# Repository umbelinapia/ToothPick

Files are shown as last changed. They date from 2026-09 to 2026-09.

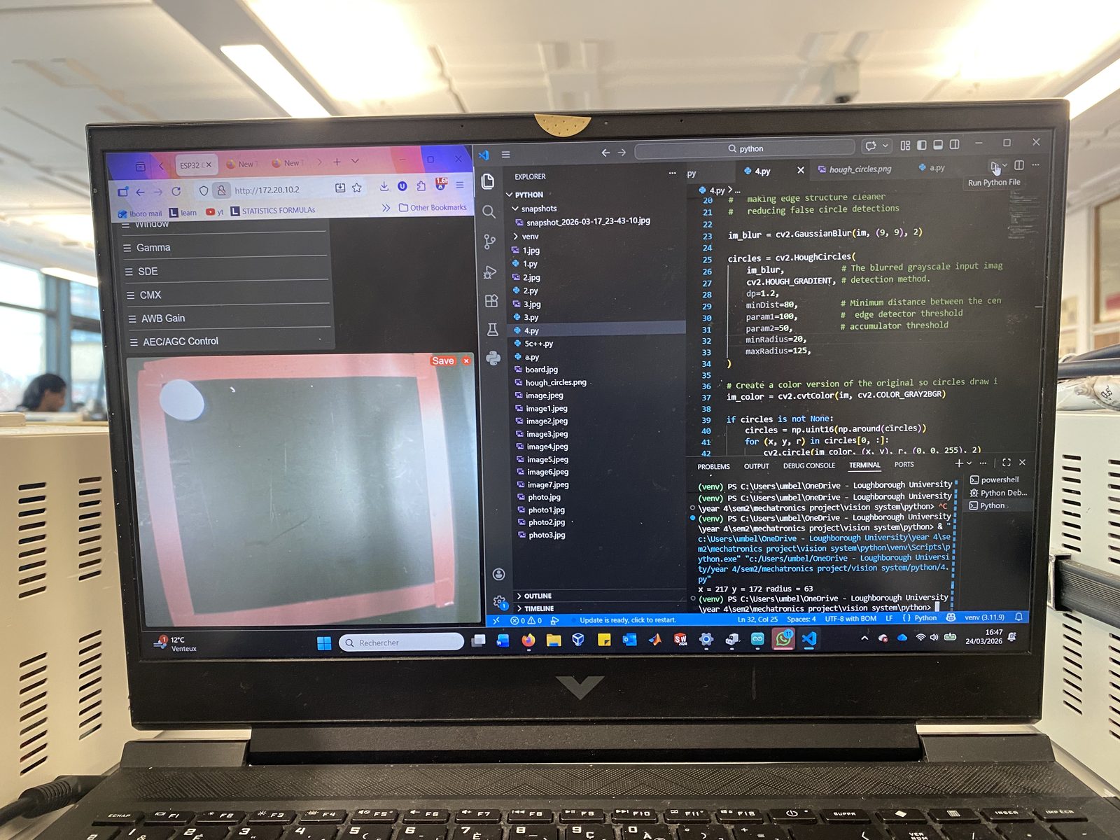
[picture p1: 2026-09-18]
evidence/photos/build-and-dev/build-03.jpg

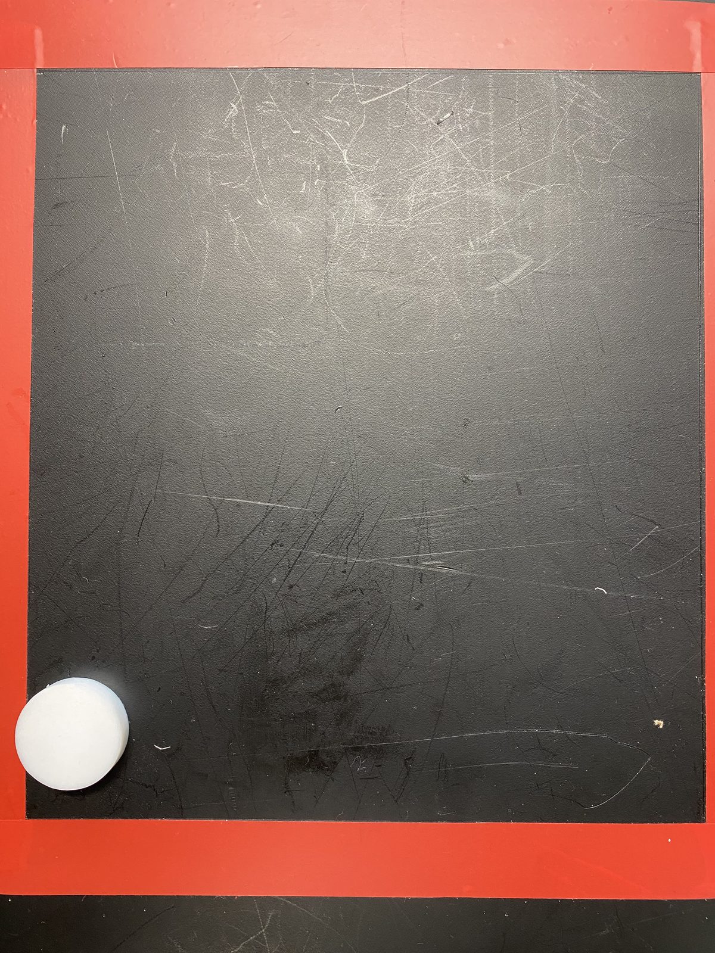
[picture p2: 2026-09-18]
evidence/photos/vision-test-captures/workspace-capture-05.jpg

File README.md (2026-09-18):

# 3rd year Mechatronics group project

## Project aim

A manufacturer's forming machine outputs plastic disc components in the
wrong orientation and an undefined location. This used to be fixed by a
worker by hand, with a 1% misorientation rate, and it's no longer safe as
the line moves to remote, unmanned automation. Our aim was to design, build,
and test an automated system that locates, flips, and places the disc
reliably, with no person in the loop.

## Project tasks

- Locate the disc using sensors (position is uncertain, so vision sensing is
  used even when not strictly required)
- Flip the disc upside down ("heads" to "tails")
- Pick up the disc and place it at a fixed destination
- Run repeatable experiments picking the disc from random starting positions

## Project objectives

- 3-DOF gantry robot built from IGUS Apiro modular drive gear units,
  controlled by an ESP32-S3
- Vision-guided disc detection (camera + OpenCV), not fixed coordinates
- Reliable, repeatable homing so every cycle starts from a known reference
- Safety interlocks so the flip/drop motions can't happen in an unsafe joint
  position
- Fast, consistent cycle time (assessed live as 4 runs in a 6-minute demo)
- Stay within the £50 build budget

## Project outcomes

Built and demonstrated a working end-to-end pipeline: home all joints, move
to a fixed camera pose, detect the disc, pick it up, home again, flip it,
move to the drop position, and place it, then reset for the next cycle. The
vision pipeline was validated against the actual part geometry (mean
diameter 25.76 mm, mean height 6.26 mm), and the full sequence was built,
tested, and demonstrated live at the Viva Voce.

## How the system works

The robot is a 3-DOF Cartesian gantry rather than an articulated arm, built
from IGUS Apiro modular drive gear units on toothed-belt rails. A gantry was
chosen over a rotary-jointed arm because each axis maps directly onto a
Cartesian/joint coordinate, so no inverse-kinematics solve is needed to
convert a target position into motor commands, which kept both the
mechanical build and the control code simpler. Three stepper motors drive
the three linear joints (J1, J2, J3), and two micro servos handle the
end-effector: one opens and closes the gripper, the other flips it between
"pick" and "drop" orientation.

**Arm control.** An ESP32-S3 runs the low-level motion firmware. Each joint
is homed against a physical limit switch before every cycle, so the robot
always starts from a known, repeatable reference position rather than
trusting wherever it happened to stop last time. Each joint also has its own
step-pulse timing, tuned individually so lighter joints move quickly without
the heavier ones losing steps. On top of that sits a small text-based
command protocol read over serial: things like `home(J1)`, `coords(J2,
speed, position)`, `open()`, `close()`, `flipUp()`, `flipDown()`, and
`cameraPose()`. Every command blocks until the arm reports back `DONE` or
`ERROR: ...`, so the caller always knows exactly when a move has actually
finished. Two safety interlocks are enforced in the firmware itself, not
just in the higher-level script: the gripper can only flip when J3 is at its
true home position, and it can only drop at the destination when J1 is at
home, the only two positions where those motions are physically safe.

**Vision.** A second ESP32-S3 with a camera module serves single frames over
Wi-Fi on request. The host laptop pulls a frame, converts it to grayscale,
applies a Gaussian blur to cut down noise, and runs a Hough Circle Transform
tuned to the disc's expected radius. Exactly one circle is expected per
frame; zero or more than one is treated as a detection failure rather than
guessed at. The detected pixel coordinate is then mapped to robot-frame
coordinates using a linear transform calibrated against the physical
workspace, with an extra correction term for the fact that the camera looks
down at an angle rather than straight overhead, which otherwise skews the
mapping near the far edge of the workspace. If the mapped position falls too
close to the front edge of the workspace, a separate "edge routine" kicks in:
the gripper approaches from the side at that boundary instead of straight
down, since a normal vertical approach would risk pushing the disc off the
edge.

**Putting it together.** The host script and the arm firmware run as two
independent loops connected only by serial (plus Wi-Fi for the camera
frames). The host's loop captures an image, processes it, and once it has a
valid detection, walks through the pick sequence one command at a time:
close the gripper, home all joints, flip up, move to the camera pose,
capture and detect, move over the disc (or run the edge routine), open,
lower, grab, return to J3 home, flip down, move to the drop position while
staying raised, lower, release, raise again, and home everything ready for
the next cycle. The arm's own loop just reads one command at a time off
serial, checks it's valid, executes it, and reports back. It has no idea
what the overall task is; it only ever sees one instruction at a time. The
blocking `DONE`/`ERROR` handshake between the two is what keeps them in
lock-step despite running on separate boards.

## Repository layout

```
firmware/     Code that runs on the two ESP32-S3 boards (arm controller + camera)
software/     Host-side (laptop) vision + pick-and-place controller
hardware/     CAD (STL exports) and component datasheets
evidence/     Documentation, presentations, measurements, build/test photos and demo video
```

Each folder has its own README with the details for that part of the
project, including the build-order history behind the final code and CAD.

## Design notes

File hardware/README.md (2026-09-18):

# Hardware

3-DOF Cartesian gantry robot:

- Gearbox drivetrain (IGUS Apiro modular drive units) on toothed-belt rails
- 3 stepper motors (joints J1/J2/J3) + 2 micro servos (gripper open/close, flip)
- Homing limit switches on every joint for a repeatable reference position
- **ESP32-S3-DEV2** as the main arm controller (compact, WiFi/Bluetooth, drives
  steppers + servos, exposes a serial command API, see [`../firmware/`](../firmware))
- Separate **ESP32-S3 AI camera module** (OV3660) for vision, wired to a
  stripboard to keep wiring permanent and minimise disconnects
- 3D-printed structural and end-effector parts

## In this folder

- [`cad/`](cad): STL exports of the team's own designed/printed parts,
  grouped by subsystem. See [`cad/README.md`](cad/README.md).
- [`datasheets/`](datasheets): component datasheets: MG90 servo dimensions,
  OV3660 camera sensor datasheet/specs, its onboard microphone, and the
  ESP32-S3 AI camera module itself.

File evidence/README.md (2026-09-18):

# Evidence

Project record: documentation, presentations, measurements, and photo/video
evidence of the build and testing process.

- [`documentation/`](documentation): [`tasks.md`](documentation/tasks.md),
  [`requirements.md`](documentation/requirements.md), [`gantt-chart.md`](documentation/gantt-chart.md)
  (who worked on what), and [`architecture-workflow.md`](documentation/architecture-workflow.md)
  (how the system works end to end). [`robot-control-logic.pdf`](documentation/robot-control-logic.pdf)
  is **my own slides**, the robot structure / vision / sequencing section of
  the group presentation was my individual share of the work, and is the
  source for `architecture-workflow.md`. [`presentations/`](documentation/presentations)
  holds the full team decks (Viva and project presentation).
- [`measurements/`](measurements): target-part measurement data.
- [`photos/`](photos): [`build-and-dev/`](photos/build-and-dev) (assembly,
  wiring, and live dev-session photos), [`vision-test-captures/`](photos/vision-test-captures)
  (raw camera captures used to tune disc detection), [`setup/`](photos/setup)
  (general camera/workspace setup shots), plus the detection output image and
  standalone build photos.
- [`videos/`](videos): a full pick, flip, place cycle demo.

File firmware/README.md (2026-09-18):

# Firmware

Code that runs directly on the two ESP32-S3 microcontrollers.

- [`arm-controller/`](arm-controller): drives the gantry robot, steppers,
  servos, homing, and the serial command API. See
  [`arm-controller/README.md`](arm-controller/README.md) for the final version
  vs. build-order iteration history.
- [`camera/`](camera): runs on the vision system's ESP32-S3 AI camera module.
  See [`camera/README.md`](camera/README.md).

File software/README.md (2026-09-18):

# Software

Host-side code, runs on a laptop, not on a microcontroller.

[`vision-pick-and-place/`](vision-pick-and-place): pulls a frame from the
camera firmware, detects the target disc with OpenCV, and drives the arm
firmware over serial through the full pick/flip/drop cycle. See
[`vision-pick-and-place/README.md`](vision-pick-and-place/README.md) for the
final version vs. iteration history.

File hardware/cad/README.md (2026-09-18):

# CAD

STL exports of the team's own designed/printed parts, grouped by subsystem.

- `base-and-drivetrain/`: base plate, mounting bracket, base gear, gear links
- `gripper-and-links/`: gripper, flipper, link, motor connectors
- `camera-mount/`: camera housing, mount, attachment point

Native CAD source files (SolidWorks `.sldprt`/`.sldasm`, Inventor `.prt`/`.iam`)
are kept separately rather than duplicated here. They're large, proprietary
formats that need the original CAD software to open, whereas the STL meshes
here can be viewed in any STL viewer or 3D-printing slicer.

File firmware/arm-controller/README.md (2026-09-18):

# Arm firmware

**Final:** [`final/arm_controller.ino`](final/arm_controller.ino), the
version that ran on the robot. Controls 3 stepper joints (J1/J2/J3) and 2
servos (gripper, flip) on an ESP32-S3, with per-joint homing, a serial
command API, and safety interlocks (flip only at true J3 home, drop only at
J1 home).

**Iterations** (`iterations/`, in build order), kept for the project record:

| Folder | What it was |
|---|---|
| `01_motor_test` | First single-motor step/pulse test |
| `02_motor_test_success` | Confirmed-working version of the same test |
| `03_umbelina_version` | First full arm sketch: joint definitions, calibration notes |
| `04_calibration` | Calibration pass on joint travel limits |
| `05_camera_serial` | Added the camera-pose move + serial handshake |
| `06_speed_test` | Experiment tightening step-pulse timing for faster motion |
| `07_umbelina_version_2` | Expanded control logic, more commands |
| `08_this_worksish` | First version with the full pick/flip/drop command set working |
| `09_umbelina_version_3` | Refined version, closest predecessor to final |
| `10_serial_heartbeat_stub` | Minimal serial "Ready/Looping" test stub, used to debug the serial link in isolation |

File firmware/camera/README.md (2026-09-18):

# Camera firmware

Runs on the vision system's ESP32-S3 AI camera module (separate board from
the arm controller).

- **`CameraWebServer.ino`**: the version actually used on the robot. Serves
  a `/capture` HTTP endpoint over Wi-Fi so the host laptop
  ([`../../software/vision-pick-and-place/`](../../software/vision-pick-and-place))
  can pull a still frame on demand.
- **`image_processing_onboard_detector.ino`**: an alternative approach that
  was prototyped, doing bright-pixel centroid detection *on the camera board
  itself* instead of sending the frame to the host. The host-side OpenCV
  pipeline is what the final system used instead.

## Note

Set your own Wi-Fi SSID/password at the top of `CameraWebServer.ino` before
flashing. The camera and host laptop need to be on the same network.

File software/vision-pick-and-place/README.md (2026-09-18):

# Vision pick-and-place controller

Runs on a host laptop, talking to two ESP32-S3 boards
([`../../firmware/`](../../firmware)):

- **Final:** [`final/pick_and_place_controller.py`](final/pick_and_place_controller.py),
  pulls a frame from the camera over HTTP, runs OpenCV Hough Circle detection
  to find the disc, maps its pixel position to robot coordinates, and drives
  the arm ([`../../firmware/arm-controller/final/arm_controller.ino`](../../firmware/arm-controller/final/arm_controller.ino))
  over serial through the full pick/flip/drop cycle.

## Iteration history

`iterations/` (numbered in build order) is the path from "can we grab a frame
and see anything" to the final integrated controller:

- `01` to `03`: basic HTTP capture from the ESP32 camera
- `04` to `07`: first circle/blob detection experiments
- `08`: scratch/draft file
- `09` to `10`: vision detection wrapped in a repeatable loop
- `11` to `12`: vision loop wired up to serial commands to the arm
- `13`: full automated infinite-loop version, immediate predecessor of
  `final/pick_and_place_controller.py`

## Detection results

[`../../evidence/photos/hough-circles-detection-output.png`](../../evidence/photos/hough-circles-detection-output.png)
is a real output frame from the detection pipeline (circle found and
annotated). [`../../evidence/photos/vision-test-captures/`](../../evidence/photos/vision-test-captures)
holds the raw top-down workspace photos, with and without the target disc,
at different positions, used to develop and tune the Hough-circle parameters
(`dp`, `minDist`, `param1`/`param2`, `minRadius`/`maxRadius` in
[`final/pick_and_place_controller.py`](final/pick_and_place_controller.py)).

See [`../../evidence/documentation/architecture-workflow.md`](../../evidence/documentation/architecture-workflow.md)
for the full pipeline diagram (image acquisition → processing → detection →
coordinate transform) and the two-loop serial handshake between this script
and the arm firmware.

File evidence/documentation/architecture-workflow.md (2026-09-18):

# Architecture / workflow

Full source diagrams: [`robot-control-logic.pdf`](robot-control-logic.pdf),
**my slides**, covering the robot structure, vision system, and task
sequencing (this section of the group presentation was my share of the
work). This is also where the repo name comes from: "toothpick" was the
project's internal codename, after the toothed-rail gantry drivetrain.

## System overview

```
        PYTHON (host laptop)                          ESP32-S3 (arm)
        ─────────────────────                          ───────────────
        image acquisition  ──HTTP GET /capture──▶  ESP32-S3 AI camera
        image processing (Gaussian blur)
        object detection (Hough circles)
        pixel → robot-frame transformation
              │
              ▼
        serial command  ───────UART────────────▶  arm control loop
        (cameraPose(), home(), open(), close(),      │
         flipUp()/flipDown(), coords(J,speed,pos))    ▼
                                                  task execution:
                                                  homing, stepper/servo motion,
                                                  safety interlocks
              ◀──────────"DONE" / "ERROR: ..."────────┘
```

## Robot structure

**Gantry robot, Cartesian configuration**, chosen over an articulated arm for
simple kinematics (no inverse-kinematics solve needed since each axis maps
directly to a Cartesian/joint coordinate), straightforward screw-and-nut
assembly, and simpler cable management along the linear rails.

## Vision pipeline

ESP32-S3 AI camera (wide-angle) → online MJPEG/HTTP stream for setup and
debugging → single-frame capture on trigger → Gaussian blur → Hough circle
detection → pixel coordinates of the detected disc → transform to robot-frame
coordinates. See [`hough-circles-detection-output.png`](../photos/hough-circles-detection-output.png)
for a real detection result, and [`vision-test-captures/`](../photos/vision-test-captures)
for the raw camera views used to develop and validate the detection routine.

## Task sequencing (two independent event loops, joined by serial + shared Wi-Fi)

**Python `loop()` (host):**
capture image → process image → cylinder detected? → no: return a warning and
retry → yes: get coordinates → execute task (send the serial command sequence
for pick/flip/place).

**Arduino `loop()` (arm):**
read serial input → is it one valid, recognised command? → no: return an
error over serial → yes: execute the command and report `DONE`.

This request/acknowledge handshake (host blocks on `DONE`/`ERROR` per command,
see `wait_for_done()` in [`pick_and_place_controller.py`](../../software/vision-pick-and-place/final/pick_and_place_controller.py))
is what keeps the two independently-running loops in lock-step despite
running on separate microcontrollers connected only by serial + a shared Wi-Fi
network for the camera link.

## Safety interlocks

- `flipUp()` / `flipDown()` only execute when J3 is at its true home switch
- `dropOpen()` only executes when J1 is at its home switch
- Both are enforced in firmware (`flipIsSafe()`, `dropIsSafe()` in
  [`arm_controller.ino`](../../firmware/arm-controller/final/arm_controller.ino)), not just in the host
  script, so a bug in the Python sequencing can't command an unsafe motion

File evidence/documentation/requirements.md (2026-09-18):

# Requirements

**Product goal:** reliably detect, pick, flip and place a cylindrical disc
without manual coordinate entry. Design drivers: accurate, repeatable,
simple; a stable structure; suited to the target environment.

## Identified requirements

- 3-DOF gantry robot with a gearbox drivetrain on toothed rails
- 3 stepper motors + 2 micro servo motors (gripper, flip)
- Homing system (limit switches) for a repeatable reference position on every cycle
- ESP32-S3-DEV2 controller: compact, sufficient processing headroom, WiFi/Bluetooth
- Stripboard wiring to keep wiring permanent and minimise disconnects
- Vision system able to locate the target disc and hand off coordinates to the arm
- Modular, adaptable, intuitive firmware functions (scalable to new end-effector routines)
- Stay within the £50 build budget

Target part, measured (see [`../measurements/disk-measurement-data.xlsx`](../measurements/disk-measurement-data.xlsx)):
mean diameter **25.76 mm**, mean height **6.26 mm** (5 samples).

## Sequencing rules (safety/consistency)

- Flipping the end-effector is only permitted when J3 is at its true home position
- Dropping (opening the gripper at the drop point) is only permitted when J1 is at home
- Every serial command blocks until the arm reports `DONE`, so each movement
  completes before the next is issued
- The homing routine re-establishes a repeatable reference position at the
  start and end of every cycle

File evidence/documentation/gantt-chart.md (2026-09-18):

# Gantt chart

Task breakdown and ownership

## Preliminary

| Task | Responsible |
|---|---|
| Success criteria definition | All |
| Workspace dimensions definition | All |
| Disc specifications definition | All |
| Requirements identification | Umbelina |
| Gantt chart | Umbelina |
| Task repartition | Umbelina |
| Camera selection | Umbelina |
| Bill of materials | All |

## Mechanical

| Task | Responsible |
|---|---|
| Layout definition vs. workspace | Umbelina |
| Arm architecture selection | Umbelina |
| Link length calculations | Umbelina |
| Reachability analysis | Umbelina |
| Flip mechanism concept design | Max |
| Gripper type selection | Max |
| Gripper CAD design | Max |
| Mounting CAD design | Max |
| CAD → print | Max |
| Order parts | Umbelina |
| Assembly | Umbelina |

## Electrical

| Task | Responsible |
|---|---|
| Power requirement calculation | Nikitha |
| Power supply selection | Nikitha |
| ESP32 configuration | Nikitha |
| End-effector actuator driver | Nikitha |
| Sensor selection | Nikitha |
| Wiring diagram | Max |
| Wiring | Umbelina |
| Cable management | Umbelina |
| Safety switch integration | Max |

## Software

| Task | Responsible |
|---|---|
| ESP32 environment setup | Nikitha |
| Motor driver interface code | Nikitha |
| Encoder reading | Nikitha |
| Joint limit implementation | Umbelina |
| Motion profiling / speed tuning | Umbelina |
| Joint control (fkine) | Umbelina |
| Kinematics (ikine) | Umbelina |
| Trajectory planning | Umbelina |
| Pick sequence routine | Umbelina |
| Flip sequence routine | Umbelina |
| Place sequence routine | Umbelina |
| Flip/drop safety interlocks (home-position gating) | Umbelina |
| Camera calibration | Umbelina |
| Workspace calibration (pixel → mm transform) | Umbelina |
| Disc detection algorithm | Umbelina |
| Coordinate transformation to robot frame | Umbelina |
| Edge-case pick routine (disc near workspace boundary) | Umbelina |

## Testing

| Task | Responsible |
|---|---|
| Single-joint test | All |
| Multi-joint coordinated motion test | All |
| Dry run without disc | All |
| Pick test | All |
| Flip test | All |
| Full pipeline test | All |

## Validation

| Task | Responsible |
|---|---|
| Accuracy measurement | Daniel |
| Flip success rate measurement | Daniel |
| Cycle time measurement | Daniel |
| System limitations analysis | All |
| Presentation preparation | All |
| Code documentation (this repo) | Umbelina |
| CAD documentation (this repo) | Umbelina |
| Oral presentation (Viva Voce) | All |

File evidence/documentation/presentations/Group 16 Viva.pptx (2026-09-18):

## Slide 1

SECTION TITLE

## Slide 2

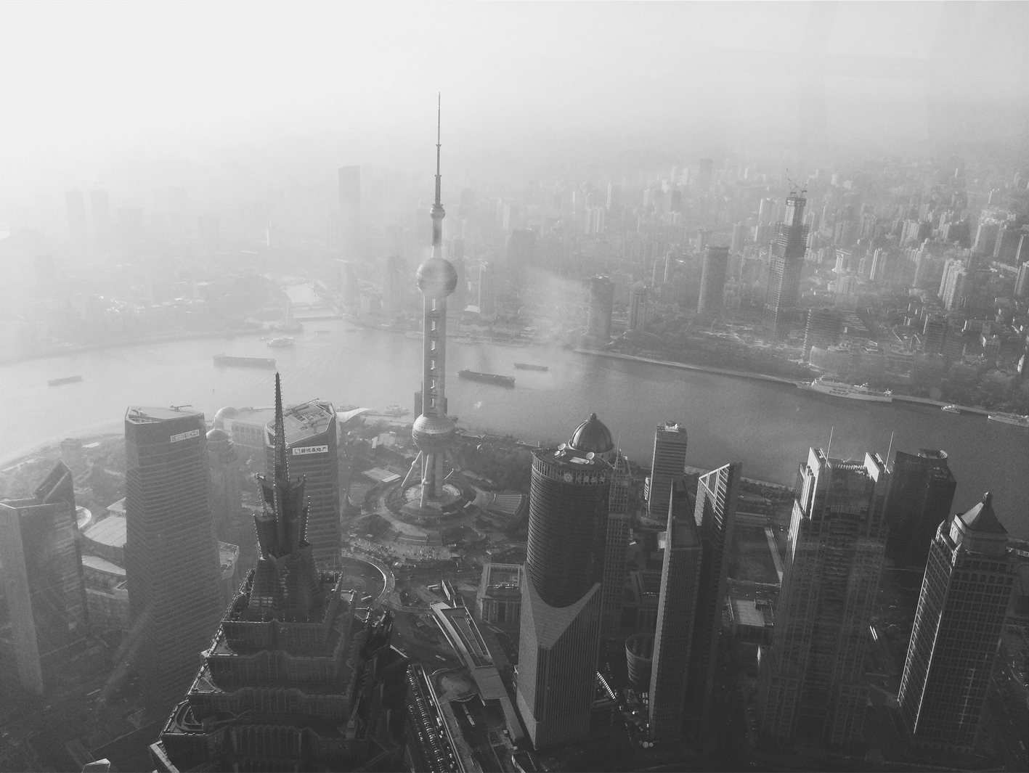
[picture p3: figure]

AUTONOMOUS CYLINDER PICK SYSTEM

CHAPTERS

PRODUCT OVERVIEW

CAMERA SEQUENCING

HARDWARE AND BASE SOFTWARE

END-EFFECTOR SEQUENCING

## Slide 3

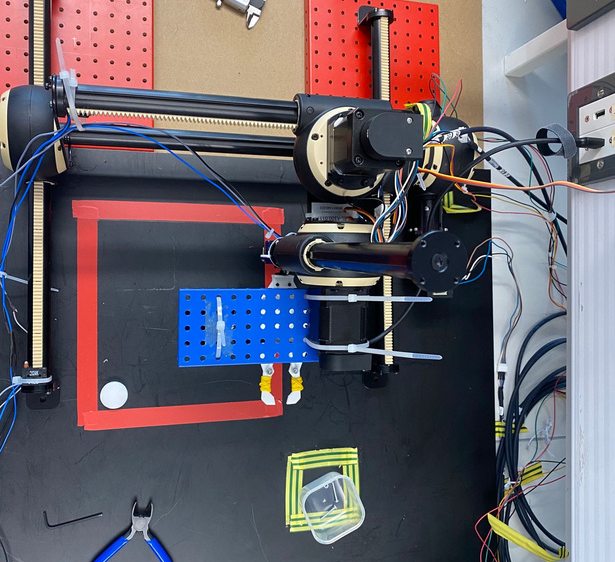
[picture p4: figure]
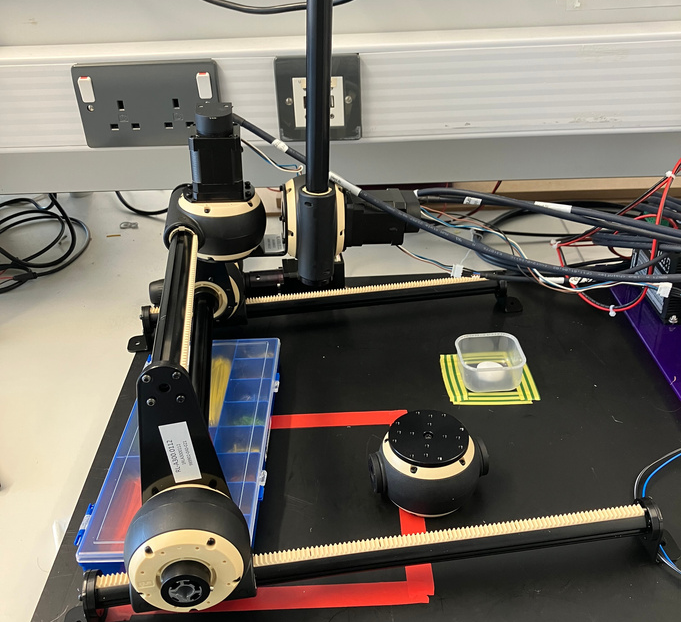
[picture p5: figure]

AUTONOMOUS CYLINDER PICK SYSTEM

OUR PRODUCT

  - 3DOF Gantry Robot
  - Gearbox with teethed rails
  - 3 Stepper Motors, 2 Servo Motors
  - Homing system

WHY?

  - Accurate, repeatable and simple
  - Stable structure
  - Ideal for environment

Daniel

caff.co

app.co

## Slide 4

Hardware and Base Software

ESP32-S3-DEV2
- Compact
- Processing Capability
- WiFi/
Bluetooth

Stripboard
- Permanent
- Less Wiring
- Minimise
Disconnect

Limit Switches
- Boundaries
- Homing

Nikitha

SECTION TWO

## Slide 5

Hardware and Base Software

2 Micro Servos
- End-Effector
- Grip and Flip

Modular Code
- Adaptable
- Intuitive
Functions
- Scalable

Homing Routine
- Consistent Positioning
- Reference

Nikitha

SECTION TWO

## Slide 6

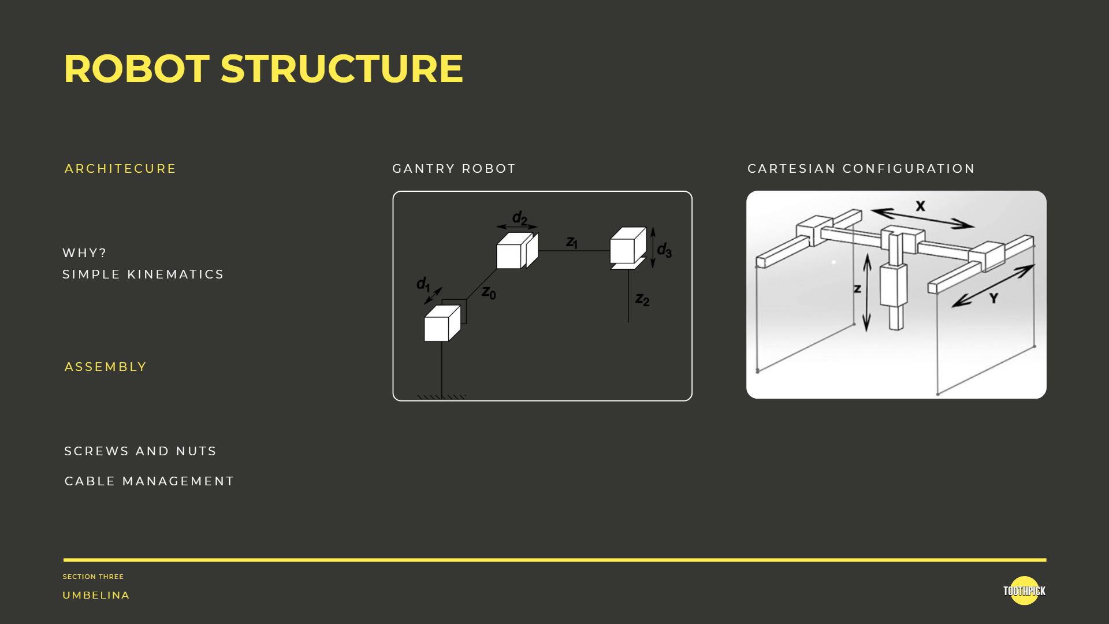
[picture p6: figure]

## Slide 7

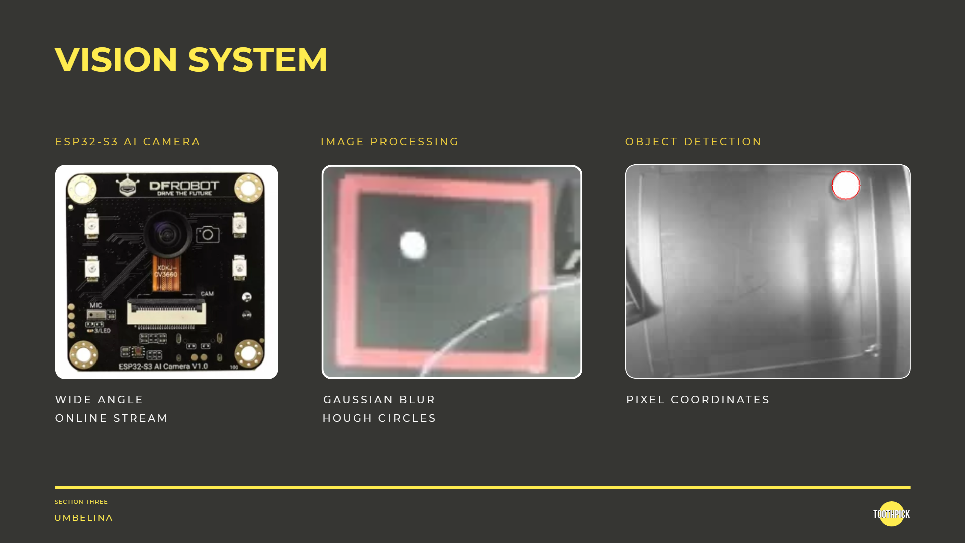
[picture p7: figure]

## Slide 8

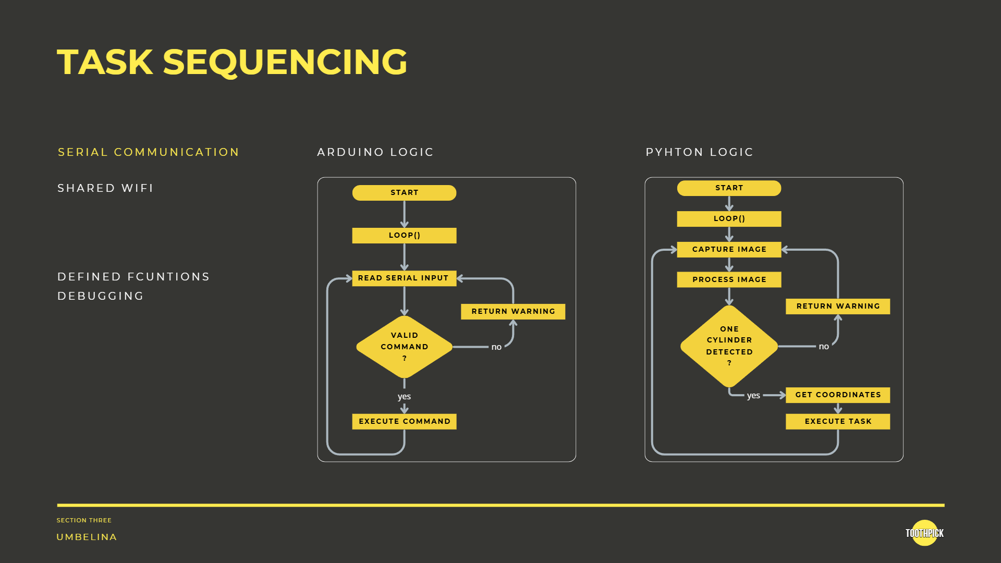
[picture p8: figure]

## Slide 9

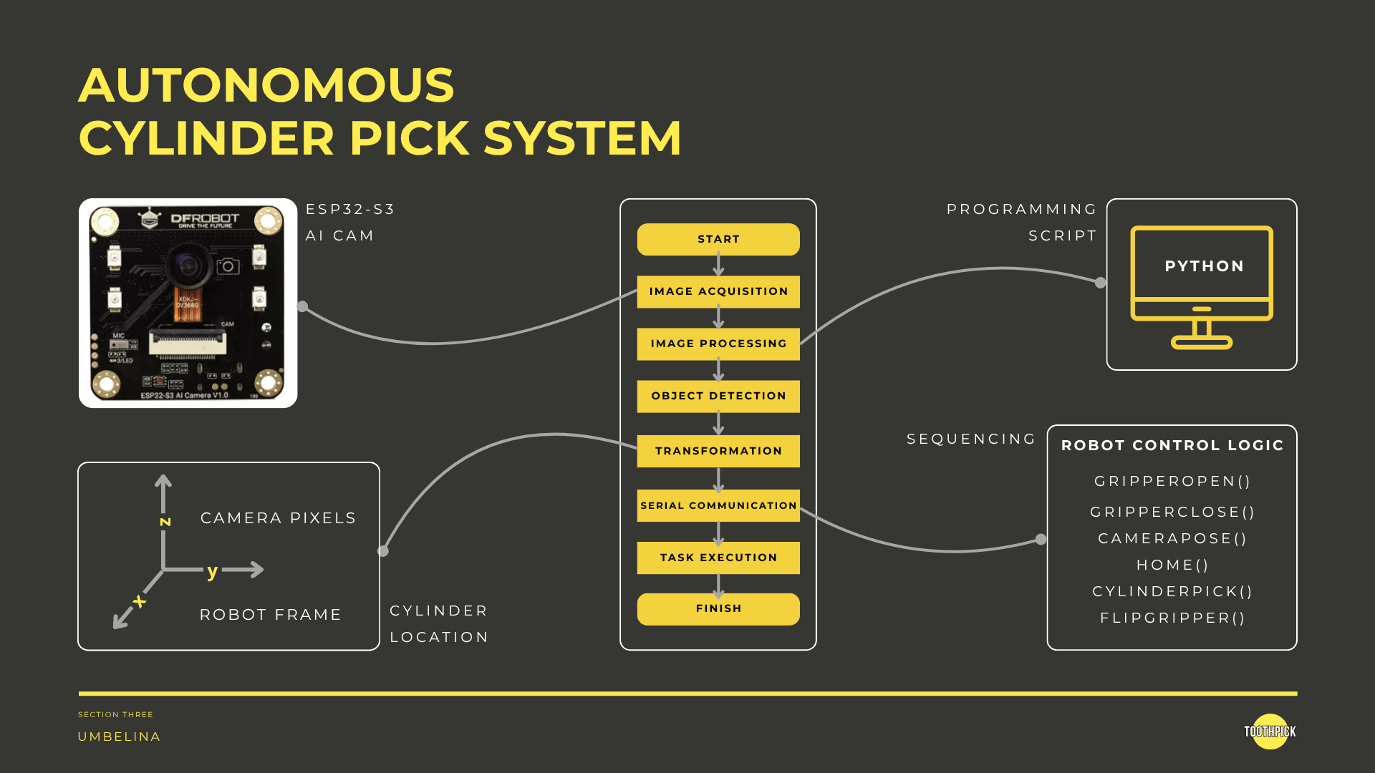
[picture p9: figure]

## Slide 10

SEQUENCE
OVERVIEW

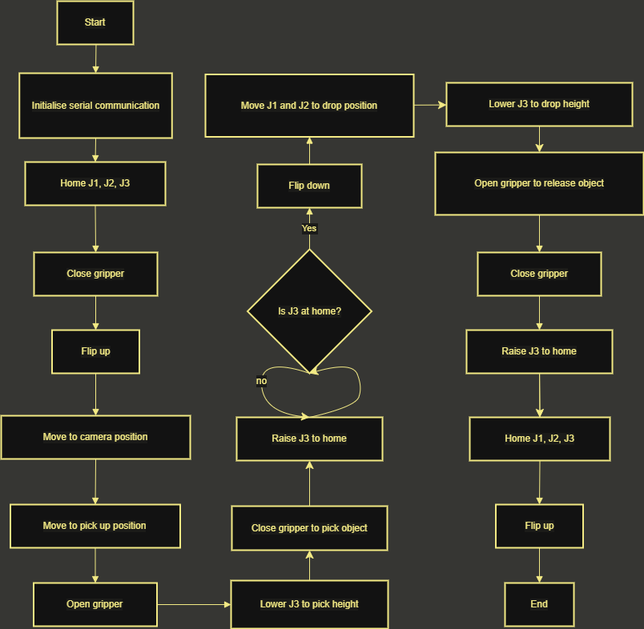
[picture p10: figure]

  - Flipping of end effector limited to when J3 is home
  - Drop limited to when J1 is at home
  - Serial ‘DONE’ ensures each movement completes before the next begins
  - Homing routine provides a repeatable reference position for every cycle

Max

SECTION FOUR

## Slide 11

End Effector

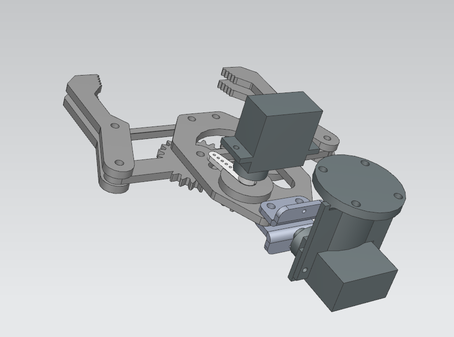
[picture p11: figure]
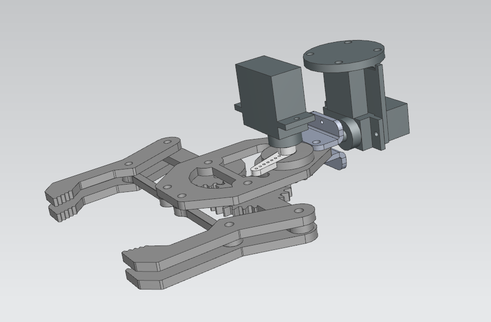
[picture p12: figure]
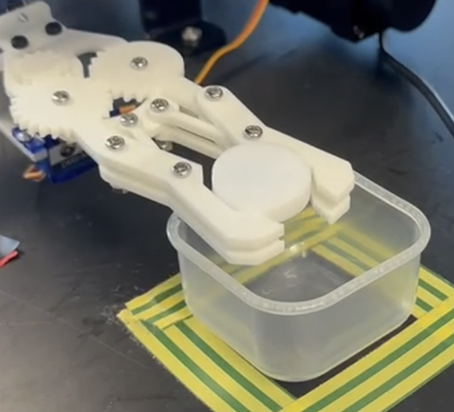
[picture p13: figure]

Max

SECTION FOUR

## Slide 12

SEE IT. PICK IT. SORT IT.

SECTION FINAL

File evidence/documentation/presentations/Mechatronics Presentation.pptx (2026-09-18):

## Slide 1

SECTION TITLE

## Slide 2


AUTONOMOUS CYLINDER PICK SYSTEM

CHAPTERS

PRODUCT OVERVIEW

CAMERA SEQUENCING

HARDWARE AND BASE SOFTWARE

END-EFFECTOR SEQUENCING

app.co

caff.co

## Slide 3


AUTONOMOUS CYLINDER PICK SYSTEM

OUR PRODUCT

  - 3DOF Gantry Robot
  - Gearbox with teethed rails
  - 3 Stepper Motors, 2 Servo Motors
  - Homing system

WHY?

  - Accurate, repeatable and simple
  - Stable structure
  - Ideal for environment

Daniel

caff.co

app.co

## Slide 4

Hardware and Base Software

ESP32-S3-DEV2
- Compact
- Processing Capability
- WiFi/
Bluetooth

Stripboard
- Permanent
- Less Wiring
- Minimise
Disconnect

nikitha

Limit Switches
- Boundaries
- Homing

SECTION TWO

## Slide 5

Hardware and Base Software

2 Micro Servos
- End-Effector
- Grip and Flip

Modular Code
- Adaptable
- Intiuitive
Functions
- Scalable

nikitha

Homing Routine
- Consistent Positioning
- Reference

SECTION TWO

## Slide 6


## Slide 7


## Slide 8


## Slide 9


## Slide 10

SEQUENCE
OVERVIEW


  - Flipping of end effector limited to when J3 is home
  - Drop limited to when J1 is at home
  - Serial ‘DONE’ ensures each movement completes before the next begins
  - Homing routine provides a repeatable reference position for every cycle

SECTION FOUR

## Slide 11

SEQUENCE
OVERVIEW


SECTION FOUR

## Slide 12

SEE IT. PICK IT. SORT IT.

SECTION FINAL

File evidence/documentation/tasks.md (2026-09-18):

# Tasks

The coursework brief (CW2, 25WSC912) set the task as: design, build, and test
a system to locate the disc, flip it upside down, and pick and place it into
a fixed destination, with sensors used to locate the disc even where its
position might otherwise be predictable, since the flip can leave it
uncertain.

Broken down for the team:

- Locate the disc using vision, not fixed coordinates
- Flip the disc upside down ("heads" to "tails")
- Pick the disc up and place it at a fixed destination
- Run repeatable experiments picking the disc from random starting positions,
  confirming the system works from an unknown start, not just a rehearsed one

Who worked on which part of the build is tracked in
[`gantt-chart.md`](gantt-chart.md).

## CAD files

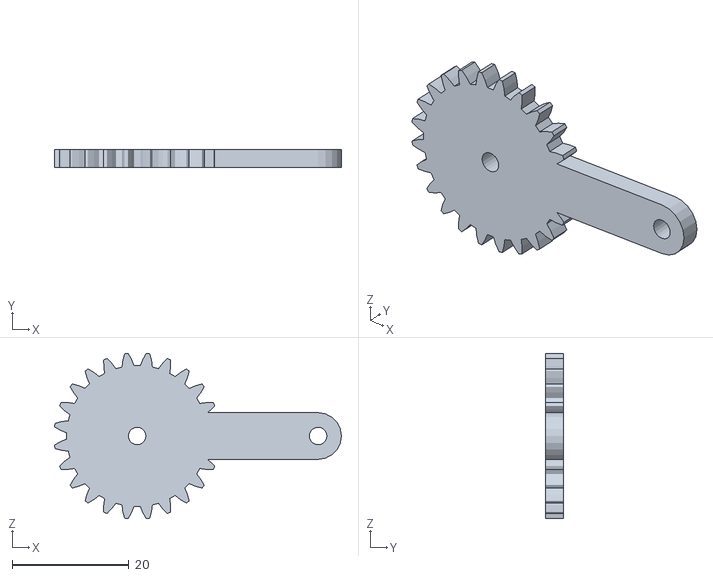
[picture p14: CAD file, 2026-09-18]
hardware/cad/stl/base-and-drivetrain/gear-link-1.stl
49.2 x 3.00 x 28.3

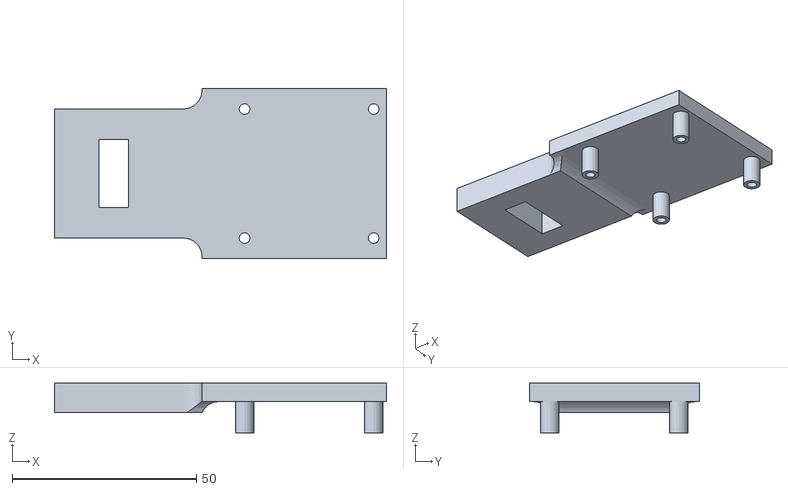
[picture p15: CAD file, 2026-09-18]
hardware/cad/stl/camera-mount/camera-housing.stl
90.0 x 46.0 x 13.5

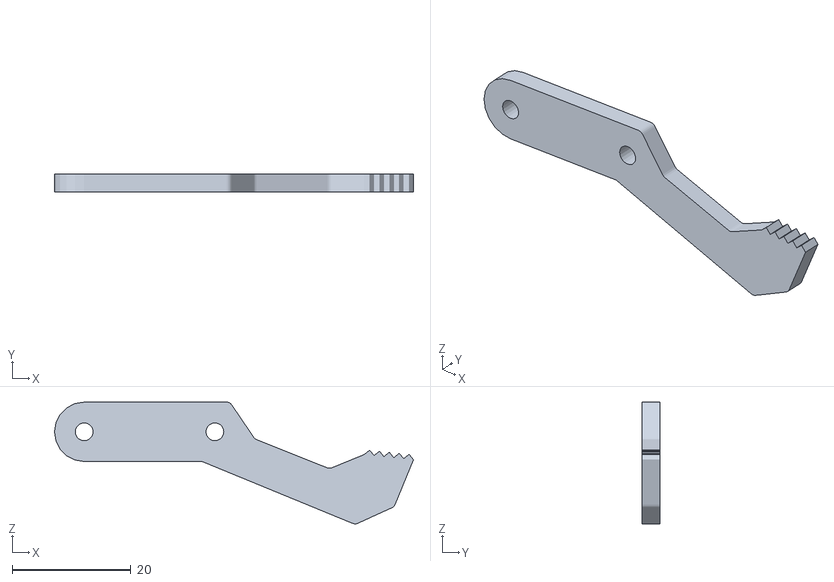
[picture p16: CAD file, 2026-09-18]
hardware/cad/stl/gripper-and-links/gripper.stl
60.4 x 3.00 x 20.5

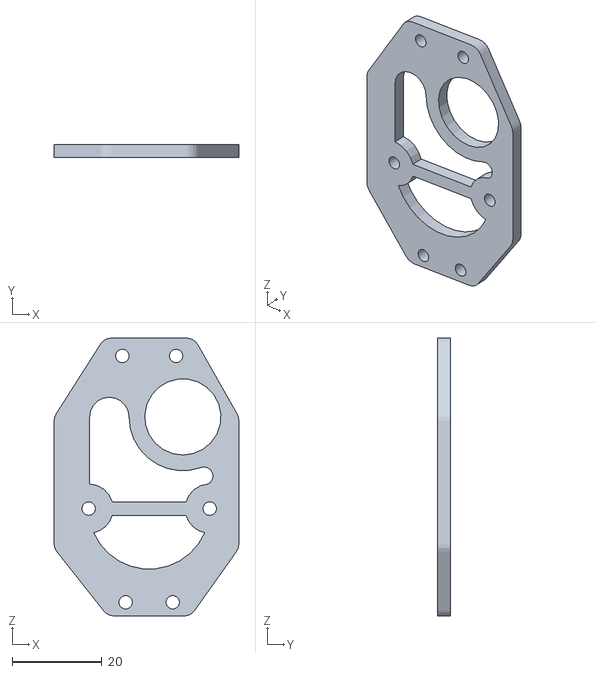
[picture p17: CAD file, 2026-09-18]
hardware/cad/stl/base-and-drivetrain/base-plate.stl
41.2 x 3.00 x 62.0

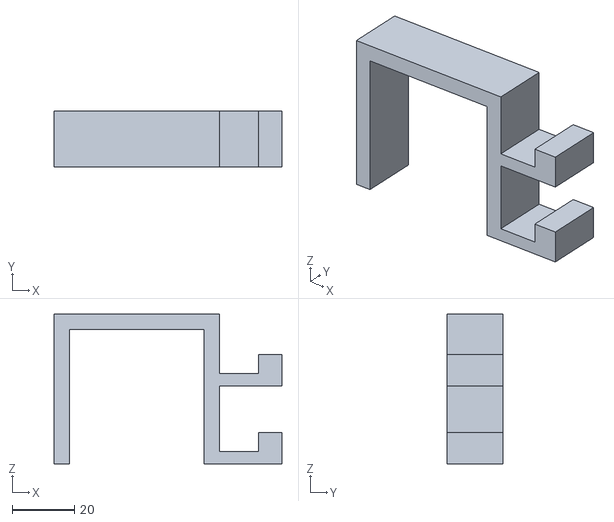
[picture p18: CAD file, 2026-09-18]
hardware/cad/stl/camera-mount/camera-mount.stl
73.0 x 18.0 x 48.0

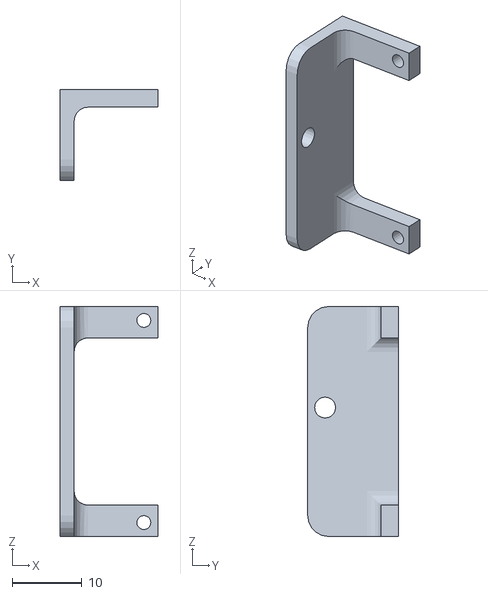
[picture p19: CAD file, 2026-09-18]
hardware/cad/stl/gripper-and-links/motor-flipper-connector.stl
14.0 x 13.0 x 33.0

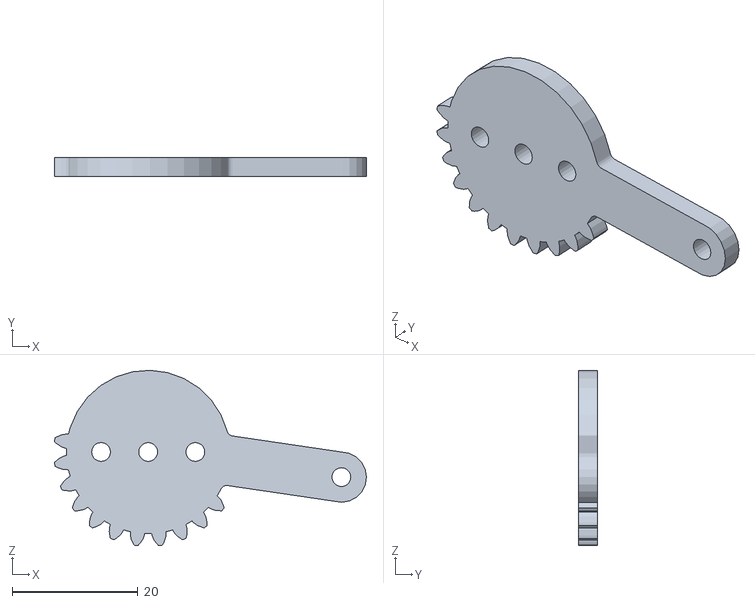
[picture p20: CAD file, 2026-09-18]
hardware/cad/stl/base-and-drivetrain/gear-link-2.stl
49.6 x 3.00 x 27.9

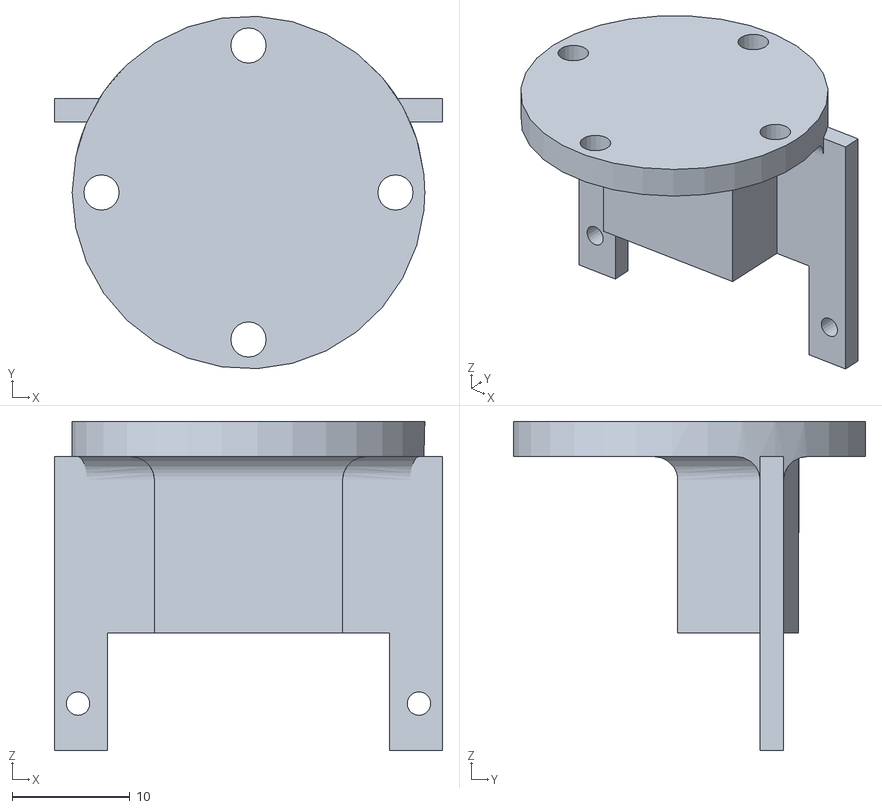
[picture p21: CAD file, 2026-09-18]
hardware/cad/stl/camera-mount/attachment-point.stl
33.0 x 30.0 x 28.0

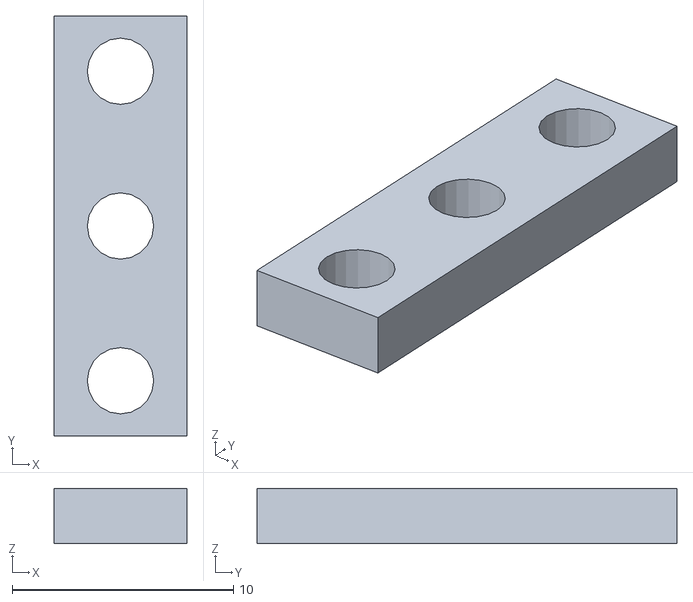
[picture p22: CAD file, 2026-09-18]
hardware/cad/stl/gripper-and-links/flipper.stl
6.00 x 19.0 x 2.50

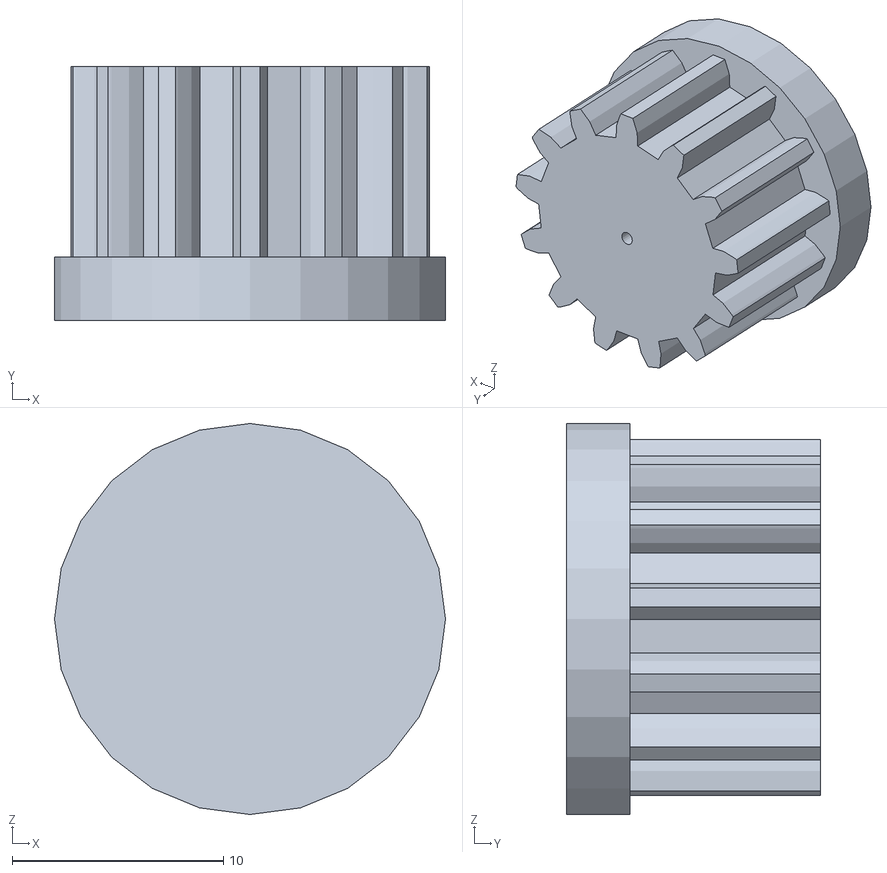
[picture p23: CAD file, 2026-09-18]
hardware/cad/stl/base-and-drivetrain/base-gear.stl
18.5 x 12.0 x 18.5

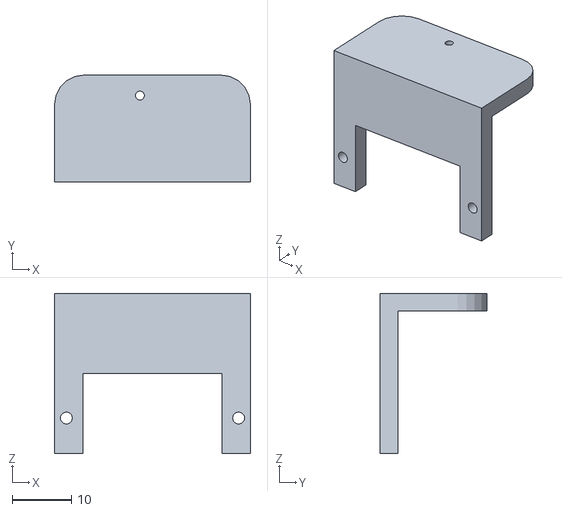
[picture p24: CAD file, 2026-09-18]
hardware/cad/stl/gripper-and-links/final-grip-motor-attach.stl
33.0 x 18.0 x 27.0

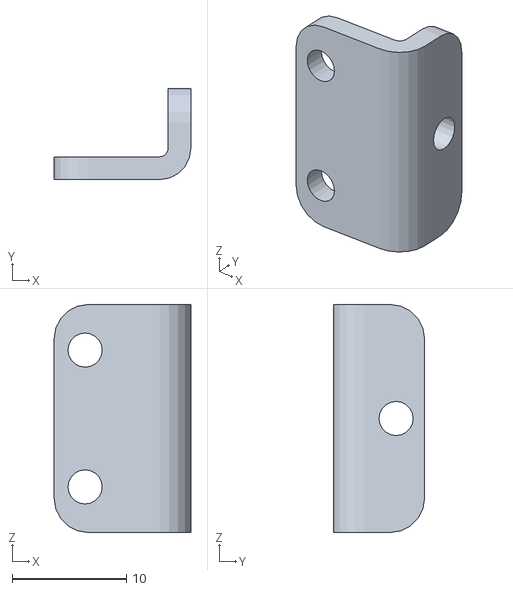
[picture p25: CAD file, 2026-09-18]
hardware/cad/stl/base-and-drivetrain/base-mounting-bracket.stl
12.0 x 8.00 x 20.0

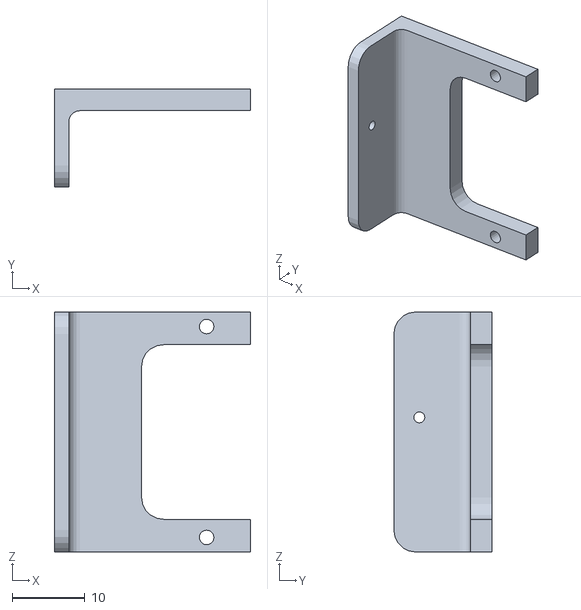
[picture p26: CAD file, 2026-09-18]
hardware/cad/stl/gripper-and-links/motor-connector.stl
27.0 x 13.5 x 33.0

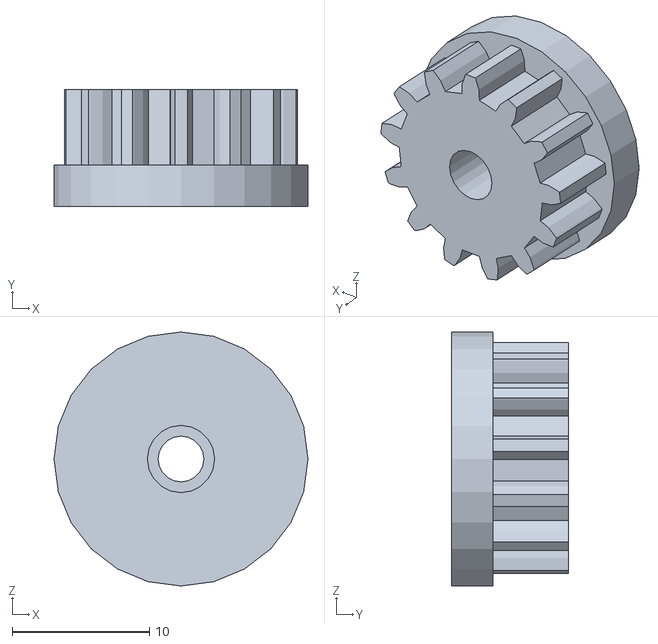
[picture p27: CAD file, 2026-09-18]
hardware/cad/stl/base-and-drivetrain/base-gear-update.stl
18.5 x 8.50 x 18.5

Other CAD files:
hardware/cad/stl/gripper-and-links/link.stl

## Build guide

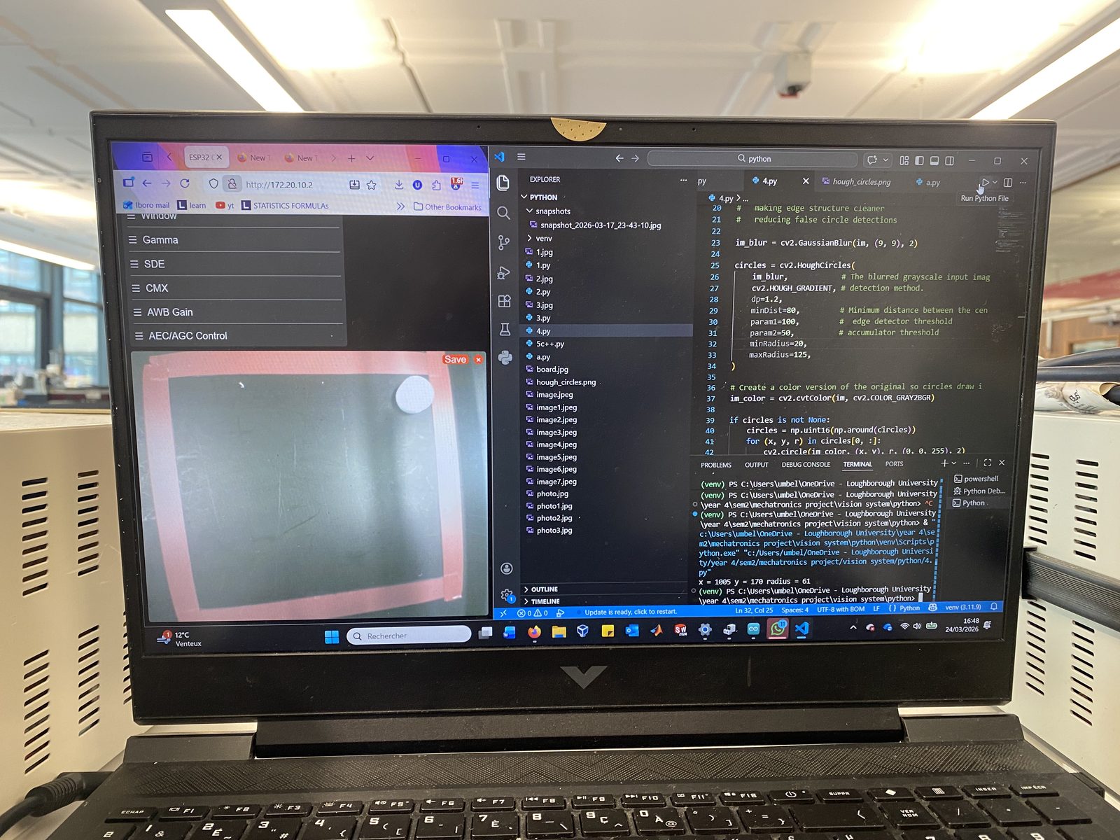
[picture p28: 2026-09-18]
evidence/photos/build-and-dev/build-06.jpg

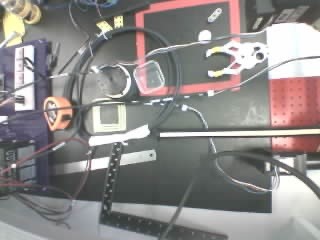
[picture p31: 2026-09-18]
evidence/photos/setup/setup-3.jpg

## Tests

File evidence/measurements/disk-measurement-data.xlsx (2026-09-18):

 | Diamiter | height
1 | 25.75 | 6.2
2 | 25.78 | 6.28
3 | 25.76 | 6.21
4 | 25.76 | 6.36
5 | 25.75 | 6.26
mean | 25.76 | 6.262

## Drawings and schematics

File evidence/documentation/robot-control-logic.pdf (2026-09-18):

# AUTONOMOUS CYLINDER PICK SYSTEM

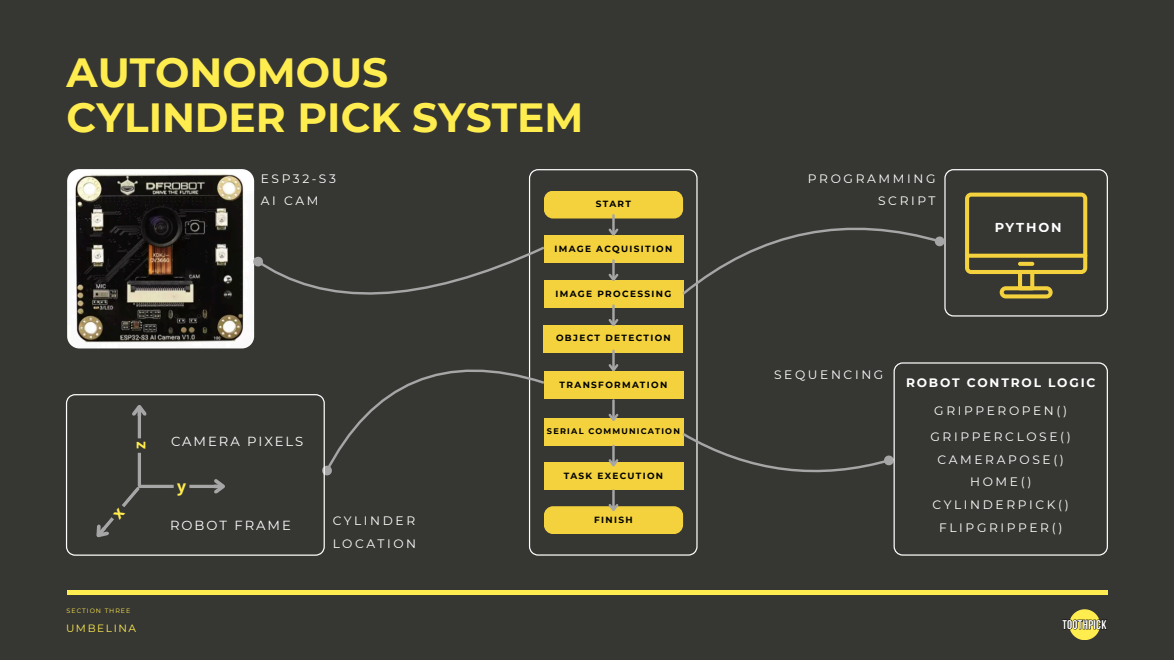
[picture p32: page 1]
START; PYT H O N; UMBEL I N A; caff.co; ttooootthhppiicckk; CAME R A PIXELS; R O B OT F R AME

IMAGE ACQ UISITI O N

IMAGE PR O C ESSI N G

O BJE CT D ETE CTI O N

T RA N SF O RMATI O N

SE R IAL COMMU N I CATI O N

TAS K E XE CUTI O N

UMBE

L I N A

# ROBOT STRUCTURE

A R C H I T E C U R E | G A N T R Y R O B O T | C A R T E S I A N C O N F I G U R A T I O N

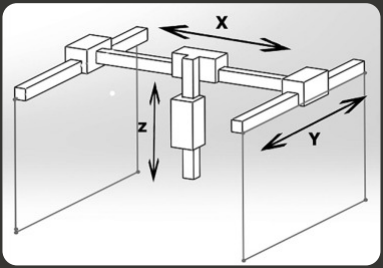
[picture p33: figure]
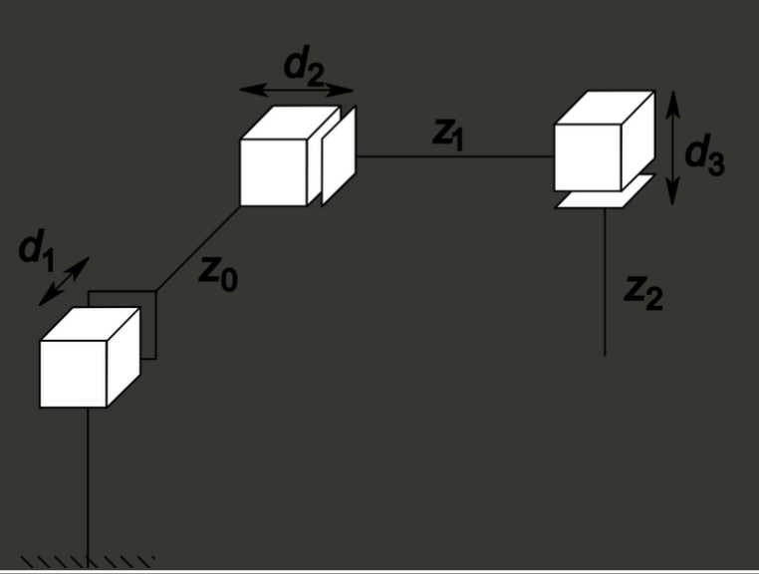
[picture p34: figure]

W H Y ?
S I M P L E K I N E M A T I C S

A S S E M B LY

S C R E W S A N D N U T S

C A B L E M A N A G E M E N T

# VISION SYSTEM

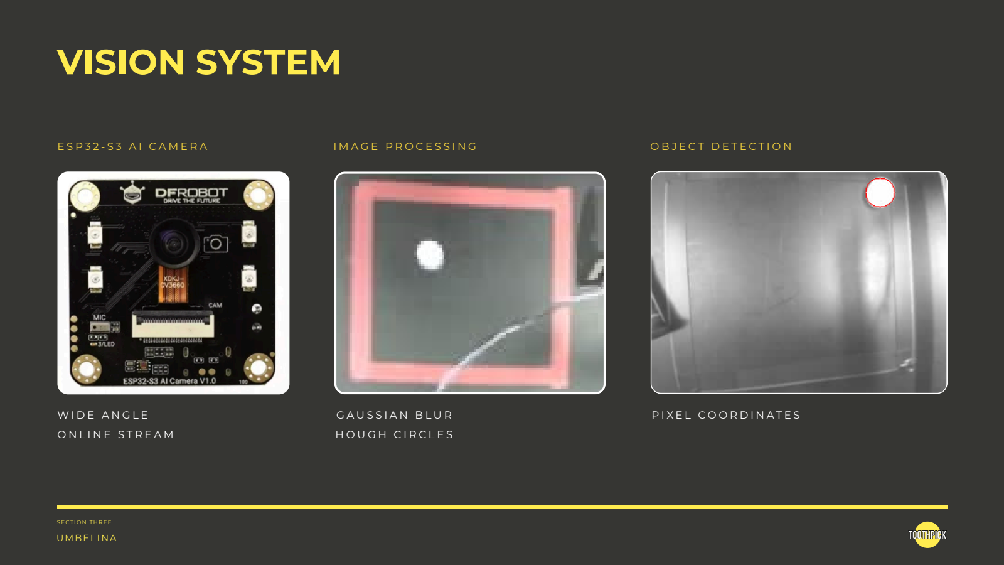
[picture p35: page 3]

UMBE

L I N A

E S P 3 2 - S 3 A I C A M E R A | I M A G E P R O C E S S I N G

G A U S S I A N B L U R
H O U G H C I R C L E S

O B J E C T D E T E C T I O N

W I D E A N G L E | P I X E L C O O R D I N A T E S
O N L I N E S T R E A M

# TASK SEQUENCING

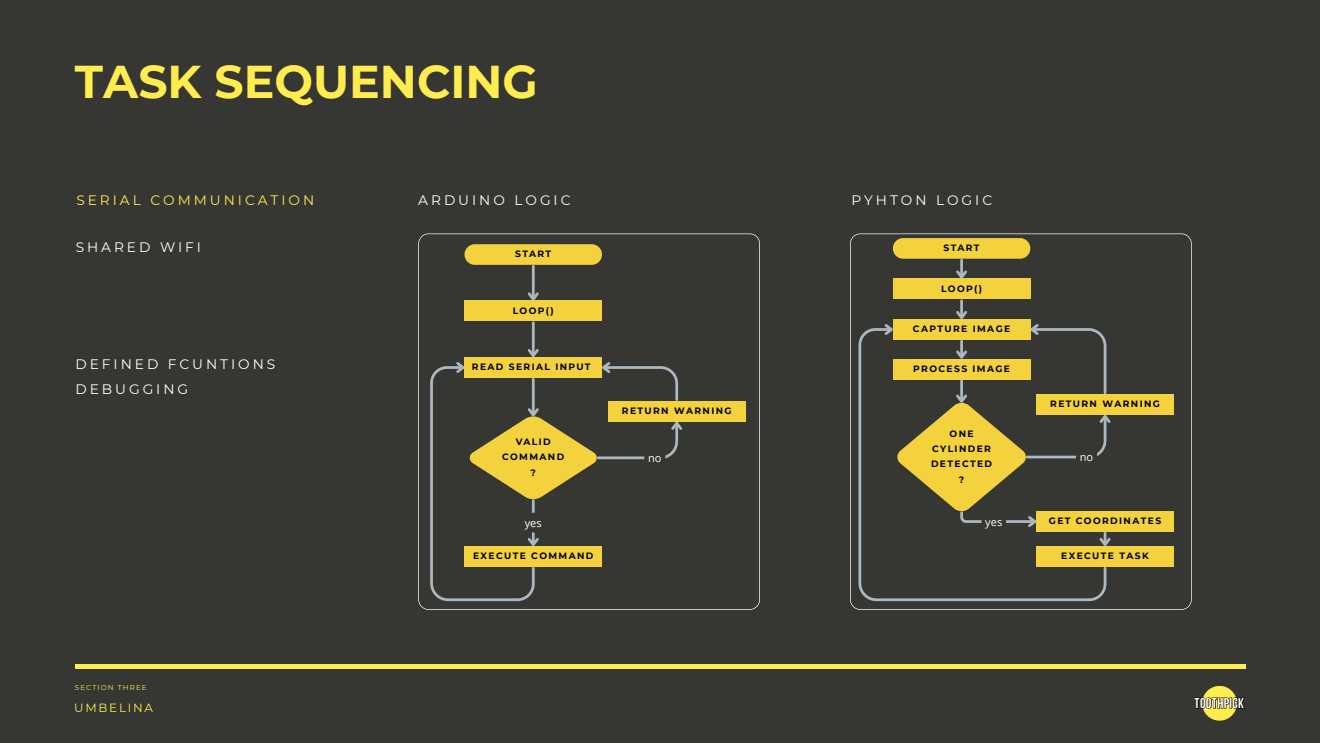
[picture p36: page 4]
UMBEL I N A; VALI D COMMA N D ?; E X E CUTE C OMMA N D; yes; START; O N E CYLI N D E R D ETE CTE D ?; E X E CUTE TAS K; P R O C ESS IMAGE; GET C O O R D I N ATES

CAP TUR E IMAGE

R EA D SE R IAL I N PUT

R ETUR N WAR N I N G

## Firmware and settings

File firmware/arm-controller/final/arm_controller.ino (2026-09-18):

#include <ESP32Servo.h>

#define PUL1 1   // J1
#define DIR1 2
#define PUL2 40  // J2
#define DIR2 39
#define PUL3 42  // J3
#define DIR3 41

#define HOME1 4
#define HOME2 5
#define HOME3 6

#define GRIP_SERVO_PIN 7
#define FLIP_SERVO_PIN 15

Servo gripServo;
Servo flipServo;

int GripOpen = 100;
int GripTightOpen = 65;
int GripClose = 0;

// Flip servo absolute positions
const int FLIP_DOWN_ANGLE = 0;
const int FLIP_UP_ANGLE   = 180;

int currentFlipAngle = FLIP_DOWN_ANGLE;

int J1_MAX = 10000;
int J2_MAX = 10150;
int J3_MAX = 700;

// Camera pose
const int CAM_J1 = 4000;
const int CAM_J2 = 8000;
const int CAM_J3 = 0;

// -----------------------------
// HOME SWITCH POLARITY
// true  = pressed reads HIGH
// false = pressed reads LOW
// -----------------------------
const bool J1_HOME_ACTIVE_HIGH = true;
const bool J2_HOME_ACTIVE_HIGH = true;
const bool J3_HOME_ACTIVE_HIGH = true;

// -----------------------------
// HOMING DIRECTION
// true  = home using motorcw()
// false = home using motorccw()
// -----------------------------
const bool J1_HOME_USES_CW = true;
const bool J2_HOME_USES_CW = true;
const bool J3_HOME_USES_CW = true;

// -----------------------------
// HOMING STEP SIZE
// -----------------------------
const int J1_HOME_STEP = 1;
const int J2_HOME_STEP = 5;
const int J3_HOME_STEP = 2;

// -----------------------------
// PER-JOINT STEP PULSE TIMING
// Bigger number = slower / gentler
// Smaller number = faster
// -----------------------------
const int J1_PULSE_US = 900;
const int J2_PULSE_US = 250;
const int J3_PULSE_US = 700;

struct Joint {
  int pul;
  int dir;
  int home;
  long pos;
  long minPos;
  long maxPos;
};

Joint J1 = {PUL1, DIR1, HOME1, 0, 0, J1_MAX};
Joint J2 = {PUL2, DIR2, HOME2, 0, 0, J2_MAX};
Joint J3 = {PUL3, DIR3, HOME3, 0, 0, J3_MAX};

String inputString = "";
bool stringComplete = false;

int getPulseDelayUs(Joint &J) {
  if (&J == &J1) return J1_PULSE_US;
  if (&J == &J2) return J2_PULSE_US;
  return J3_PULSE_US;
}

bool switchPressed(Joint &J) {
  bool activeHigh = true;

  if (&J == &J1) activeHigh = J1_HOME_ACTIVE_HIGH;
  else if (&J == &J2) activeHigh = J2_HOME_ACTIVE_HIGH;
  else if (&J == &J3) activeHigh = J3_HOME_ACTIVE_HIGH;

  int state = digitalRead(J.home);
  return activeHigh ? (state == HIGH) : (state == LOW);
}

bool jointIsHome(Joint &J) {
  return switchPressed(J);
}

void motorcw(Joint &J, int rotate) {
  int pulseUs = getPulseDelayUs(J);

  digitalWrite(J.dir, LOW);
  for (int i = 0; i < rotate; i++) {
    digitalWrite(J.pul, HIGH);
    delayMicroseconds(pulseUs);
    digitalWrite(J.pul, LOW);
    delayMicroseconds(pulseUs);
    J.pos--;
  }
}

void motorccw(Joint &J, int rotate) {
  int pulseUs = getPulseDelayUs(J);

  digitalWrite(J.dir, HIGH);
  for (int i = 0; i < rotate; i++) {
    digitalWrite(J.pul, HIGH);
    delayMicroseconds(pulseUs);
    digitalWrite(J.pul, LOW);
    delayMicroseconds(pulseUs);
    J.pos++;
  }
}

void moveTowardHome(Joint &J, int stepSize) {
  bool useCW = true;

  if (&J == &J1) useCW = J1_HOME_USES_CW;
  else if (&J == &J2) useCW = J2_HOME_USES_CW;
  else if (&J == &J3) useCW = J3_HOME_USES_CW;

  if (useCW) {
    motorcw(J, stepSize);
  } else {
    motorccw(J, stepSize);
  }
}

int getHomeStepSize(Joint &J) {
  if (&J == &J1) return J1_HOME_STEP;
  if (&J == &J2) return J2_HOME_STEP;
  return J3_HOME_STEP;
}

// Returns true only if the switch was actually reached
bool homing(Joint &J) {
  unsigned long startTime = millis();
  const unsigned long HOME_TIMEOUT_MS = 20000;
  int stepSize = getHomeStepSize(J);

  Serial.println("Starting homing...");
  Serial.print("Initial switch state: ");
  Serial.println(digitalRead(J.home));

  if (switchPressed(J)) {
    J.pos = 0;
    Serial.println("Already on home switch.");
    Serial.println("Homing complete.");
    return true;
  }

  while (!switchPressed(J)) {
    moveTowardHome(J, stepSize);

    if (millis() - startTime > HOME_TIMEOUT_MS) {
      Serial.println("ERROR: homing timeout");
      return false;
    }
  }

  J.pos = 0;

  Serial.print("Final switch state: ");
  Serial.println(digitalRead(J.home));
  Serial.println("Homing complete.");
  return true;
}

void FlipGripper(int angle) {
  flipServo.write(angle);
  currentFlipAngle = angle;
}

void GripperOpen() {
  gripServo.write(GripOpen);
}

void GripperTightOpen() {
  gripServo.write(GripTightOpen);
}

void GripperClose() {
  gripServo.write(GripClose);
}

bool coords(Joint &J, int rotate, long coord) {
  if (coord < J.minPos || coord > J.maxPos) {
    Serial.print("ERROR: target out of range. Allowed: ");
    Serial.print(J.minPos);
    Serial.print(" to ");
    Serial.println(J.maxPos);
    return false;
  }

  if (rotate <= 0) {
    Serial.println("ERROR: rotate must be > 0");
    return false;
  }

  if (J.pos == coord) return true;

  while (J.pos < coord) {
    long remaining = coord - J.pos;
    int step = (remaining > rotate) ? rotate : (int)remaining;
    motorccw(J, step);
  }

  while (J.pos > coord) {
    long remaining = J.pos - coord;
    int step = (remaining > rotate) ? rotate : (int)remaining;
    motorcw(J, step);
  }

  delay(50);
  return true;
}

bool cameraPose() {
  if (!coords(J1, 250, CAM_J1)) return false;
  if (!coords(J2, 250, CAM_J2)) return false;
  if (!coords(J3, 50, CAM_J3)) return false;
  return true;
}

Joint* getJointByName(String name) {
  name.trim();
  if (name == "J1") return &J1;
  if (name == "J2") return &J2;
  if (name == "J3") return &J3;
  return nullptr;
}

void printPositions() {
  Serial.print("J1 pos = ");
  Serial.println(J1.pos);
  Serial.print("J2 pos = ");
  Serial.println(J2.pos);
  Serial.print("J3 pos = ");
  Serial.println(J3.pos);

  Serial.print("HOME1 = ");
  Serial.println(digitalRead(HOME1));
  Serial.print("HOME2 = ");
  Serial.println(digitalRead(HOME2));
  Serial.print("HOME3 = ");
  Serial.println(digitalRead(HOME3));

  Serial.print("J1 at home = ");
  Serial.println(jointIsHome(J1) ? "YES" : "NO");
  Serial.print("J2 at home = ");
  Serial.println(jointIsHome(J2) ? "YES" : "NO");
  Serial.print("J3 at home = ");
  Serial.println(jointIsHome(J3) ? "YES" : "NO");
}

bool j1HomeSwitchPressed() {
  return switchPressed(J1);
}

bool dropIsSafe() {
  return j1HomeSwitchPressed();
}

// -----------------------------
// flipping is ONLY allowed when J3 home switch is pressed
// -----------------------------
bool flipIsSafe() {
  return jointIsHome(J3);
}

void executeCommand(String cmd) {
  cmd.trim();
  if (cmd.length() == 0) return;

  Serial.print("Received: ");
  Serial.println(cmd);

  if (cmd.startsWith("coords(") && cmd.endsWith(")")) {
    int start = cmd.indexOf('(');
    int end = cmd.lastIndexOf(')');
    String inside = cmd.substring(start + 1, end);

    int c1 = inside.indexOf(',');
    int c2 = inside.indexOf(',', c1 + 1);

    if (c1 == -1 || c2 == -1) {
      Serial.println("ERROR: invalid coords format. Use coords(J2,100,8000)");
      return;
    }

    String jointName = inside.substring(0, c1);
    String rotateStr = inside.substring(c1 + 1, c2);
    String coordStr = inside.substring(c2 + 1);

    Joint* joint = getJointByName(jointName);
    if (joint == nullptr) {
      Serial.println("ERROR: invalid joint. Use J1, J2, or J3.");
      return;
    }

    int rotate = rotateStr.toInt();
    long coord = coordStr.toInt();

    if (coords(*joint, rotate, coord)) {
      Serial.println("DONE");
    }
    return;
  }

  if (cmd.startsWith("home(") && cmd.endsWith(")")) {
    int start = cmd.indexOf('(');
    int end = cmd.lastIndexOf(')');
    String jointName = cmd.substring(start + 1, end);

    Joint* joint = getJointByName(jointName);
    if (joint == nullptr) {
      Serial.println("ERROR: invalid joint. Use J1, J2, or J3.");
      return;
    }

    if (homing(*joint)) {
      Serial.println("DONE");
    }
    return;
  }

  if (cmd == "opentight()") {
    GripperTightOpen();
    Serial.println("DONE");
    return;
  }

  if (cmd == "open()") {
    GripperOpen();
    Serial.println("DONE");
    return;
  }

  if (cmd == "dropOpen()") {
    if (!dropIsSafe()) {
      Serial.print("ERROR: drop blocked. J1 switch not pressed. HOME1 = ");
      Serial.println(digitalRead(HOME1));
      return;
    }

    GripperOpen();
    Serial.println("DONE");
    return;
  }

  if (cmd == "close()") {
    GripperClose();
    Serial.println("DONE");
    return;
  }

  if (cmd == "flipUp()") {
    if (!flipIsSafe()) {
      Serial.print("ERROR: flip blocked. J3 not at true home. HOME3 = ");
      Serial.print(digitalRead(HOME3));
      Serial.print(" J3 pos = ");
      Serial.println(J3.pos);
      return;
    }

    FlipGripper(FLIP_UP_ANGLE);
    Serial.println("DONE");
    return;
  }

  if (cmd == "flipDown()") {
    if (!flipIsSafe()) {
      Serial.print("ERROR: flip blocked. J3 not at true home. HOME3 = ");
      Serial.print(digitalRead(HOME3));
      Serial.print(" J3 pos = ");
      Serial.println(J3.pos);
      return;
    }

    FlipGripper(FLIP_DOWN_ANGLE);
    Serial.println("DONE");
    return;
  }

  if (cmd == "flip()") {
    if (!flipIsSafe()) {
      Serial.print("ERROR: flip blocked. J3 not at true home. HOME3 = ");
      Serial.print(digitalRead(HOME3));
      Serial.print(" J3 pos = ");
      Serial.println(J3.pos);
      return;
    }

    if (currentFlipAngle == FLIP_UP_ANGLE) {
      FlipGripper(FLIP_DOWN_ANGLE);
    } else {
      FlipGripper(FLIP_UP_ANGLE);
    }

    Serial.println("DONE");
    return;
  }

  if (cmd == "pos()") {
    printPositions();
    Serial.println("DONE");
    return;
  }

  if (cmd == "cameraPose()") {
    if (cameraPose()) {
      Serial.println("DONE");
    }
    return;
  }

  Serial.println("ERROR: unknown command");
}

void readSerialInput() {
  while (Serial.available()) {
    char inChar = (char)Serial.read();

    if (inChar == '\n' || inChar == '\r') {
      if (inputString.length() > 0) {
        stringComplete = true;
      }
    } else {
      inputString += inChar;
    }
  }
}

void setup() {
  pinMode(PUL1, OUTPUT);
  pinMode(DIR1, OUTPUT);
  pinMode(PUL2, OUTPUT);
  pinMode(DIR2, OUTPUT);
  pinMode(PUL3, OUTPUT);
  pinMode(DIR3, OUTPUT);

  pinMode(HOME1, INPUT_PULLUP);
  pinMode(HOME2, INPUT_PULLUP);
  pinMode(HOME3, INPUT_PULLUP);

  Serial.begin(115200);
  delay(3000);
  Serial.println("Ready.");

  gripServo.attach(GRIP_SERVO_PIN, 500, 2400);
  flipServo.attach(FLIP_SERVO_PIN, 500, 2400);

  GripperOpen();
  FlipGripper(FLIP_DOWN_ANGLE);

  inputString.reserve(100);

  Serial.println("Commands:");
  Serial.println("  open()");
  Serial.println("  dropOpen()");
  Serial.println("  close()");
  Serial.println("  flipUp()");
  Serial.println("  flipDown()");
  Serial.println("  flip()");
  Serial.println("  home(J1)");
  Serial.println("  home(J2)");
  Serial.println("  home(J3)");
  Serial.println("  coords(J2,100,8000)");
  Serial.println("  cameraPose()");
  Serial.println("  pos()");
  Serial.println("DONE is only printed on real success.");
}

void loop() {
  readSerialInput();

  if (stringComplete) {
    executeCommand(inputString);
    inputString = "";
    stringComplete = false;
  }
}

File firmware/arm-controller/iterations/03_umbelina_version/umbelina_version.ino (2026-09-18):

//Nikitha Prabhakar
//20/03/26
//Caqlliobration

//30-1.7 j1
//30-12= ? 17.5? j2
//9.8- 0.5 j3

/*motorccw(J1, 9250);
  motorccw(J2, 9250);
  motorccw(J3, 1200);*/
#include <ESP32Servo.h>

#define PUL1 1 //J1
#define DIR1 2
#define PUL2 40 //J2
#define DIR2 39
#define PUL3 42 //J2
#define DIR3 41

#define HOME1 4
#define HOME2 5
#define HOME3 6

#define GRIP_SERVO_PIN 7
#define FLIP_SERVO_PIN 15

Servo gripServo;
Servo flipServo;

bool flipState = false;

int rotate = 0;
int FlipHome = 0;
int FlipAngle = 180;
int GripOpen = 0;
int GripClose = 180;

int J1_MAX = 10000;
int J2_MAX = 10150;
int J3_MAX = 625;

const int CAM_J1 = 3750;
const int CAM_J2 = 8000;
const int CAM_J3 = 0;


struct Joint {
  int pul;
  int dir;
  int home;
  long pos;
  long minPos;
  long maxPos;
};

Joint J1 = {PUL1, DIR1, HOME1, 0, 0, J1_MAX};
Joint J2 = {PUL2, DIR2, HOME2, 0, 0, J2_MAX};
Joint J3 = {PUL3, DIR3, HOME3, 0, 0, J3_MAX};

//delete
String inputString = "";
bool stringComplete = false;

void setup() {
  pinMode(PUL1, OUTPUT);
  pinMode(DIR1, OUTPUT);
  pinMode(PUL2, OUTPUT);
  pinMode(DIR2, OUTPUT);
  pinMode(PUL3, OUTPUT);
  pinMode(DIR3, OUTPUT);
  pinMode(HOME1, INPUT);
  pinMode(HOME2, INPUT);
  pinMode(HOME3, INPUT);

  Serial.begin(115200);

  gripServo.attach(GRIP_SERVO_PIN, 500, 2400);
  flipServo.attach(FLIP_SERVO_PIN, 500, 2400);

  inputString.reserve(100);

  Serial.println("Ready.");
  Serial.println("Example commands:");
  Serial.println("coords(J2,100,8000)");
  Serial.println("home(J1)");
  Serial.println("open()");
  Serial.println("close()");
  Serial.println("flip()");
  Serial.println("pos()");
}

//motorcw(J1, 100)
void motorcw(Joint &J,int rotate) {
  //direction LOW is Clockwise
  //direction HIGH is Anti-clockwise
  digitalWrite(J.dir, LOW);

  //pulse is the control signal
  for (int i = 0; i < rotate; i++) {
    digitalWrite(J.pul, HIGH);
    delayMicroseconds(500);
    digitalWrite(J.pul, LOW);
    delayMicroseconds(500);
    J.pos--;
  }
}

//motorccw(J1, 100)
void motorccw(Joint &J,int rotate) {
  //direction LOW is Clockwise
  //direction HIGH is Anti-clockwise
  digitalWrite(J.dir, HIGH);

  //pulse is the control signal
  for (int i = 0; i < rotate; i++) {
    digitalWrite(J.pul, HIGH);
    delayMicroseconds(500);
    digitalWrite(J.pul, LOW);
    delayMicroseconds(500);
    J.pos++;
    Serial.println(J.pos);
  }
}

//homing(J1, 100)
void homing(Joint &J,int rotate) {
  while (digitalRead(J.home) == LOW){
    Serial.println(digitalRead(J.home));
    motorcw(J, rotate);
    
  }
  J.pos = 0;

}



//enc_cal(J1, 100, CountA1);
void pos_cal(Joint &J,int rotate, volatile long &count) {
  count = 0;
  motorcw(J, rotate);
  Serial.print("rotations: ");
  Serial.println(rotate);
}

// FlipGripper()
void FlipGripper() {
  if (flipState == false) {
    flipServo.write(FlipAngle);
    flipState = true;
  } else {
    flipServo.write(FlipHome);
    flipState = false;
  }
}

//GripperOpen()
void GripperOpen(){
  gripServo.write(GripOpen);
  }

//GripperClose()
void GripperClose(){
  gripServo.write(GripClose);
  }
//set the coordinates for camera IN PROGRESS
void cameraPose(){
  coords(J1, 50, CAM_J1);
  coords(J2, 50, CAM_J2);
  coords(J3, 50, CAM_J3);
}

//coords(J1, rotations, coord for joint)
void coords(Joint &J,int rotate, int coord){
  
  if (coord < J.minPos || coord > J.maxPos) {
    Serial.print("ERROR: ");
    Serial.print(" target out of range. Allowed: ");
    Serial.print(J.minPos);
    Serial.print(" to ");
    Serial.println(J.maxPos);
    return;
  }

  while (J.pos < coord) {
    // motorccw(J, rotate);
    
    //delete
    int remaining = coord - J.pos;
    int step = (remaining > rotate) ? rotate : remaining;
    motorccw(J, step);
  }

  while (J.pos> coord){
    // motorcw(J, rotate);

    //delete
    int remaining = coord - J.pos;
    int step = (remaining > rotate) ? rotate : remaining;
    motorccw(J, step);
  }
  delay(2000);

}

//delete

Joint* getJointByName(String name) {
  name.trim();

  if (name == "J1") return &J1;
  if (name == "J2") return &J2;
  if (name == "J3") return &J3;

  return nullptr;
}

void printPositions() {
  Serial.print("J1 pos = ");
  Serial.println(J1.pos);

  Serial.print("J2 pos = ");
  Serial.println(J2.pos);

  Serial.print("J3 pos = ");
  Serial.println(J3.pos);
}

//delete
void executeCommand(String cmd) {
  cmd.trim();

  if (cmd.length() == 0) return;

  Serial.print("Received: ");
  Serial.println(cmd);

  // coords(J2,100,8000)
  if (cmd.startsWith("coords(") && cmd.endsWith(")")) {
    int start = cmd.indexOf('(');
    int end = cmd.lastIndexOf(')');
    String inside = cmd.substring(start + 1, end);

    int c1 = inside.indexOf(',');
    int c2 = inside.indexOf(',', c1 + 1);

    if (c1 == -1 || c2 == -1) {
      Serial.println("Invalid coords format. Use: coords(J2,100,8000)");
      return;
    }

    String jointName = inside.substring(0, c1);
    String rotateStr = inside.substring(c1 + 1, c2);
    String coordStr = inside.substring(c2 + 1);

    Joint* joint = getJointByName(jointName);
    if (joint == nullptr) {
      Serial.println("Invalid joint. Use J1, J2, or J3.");
      return;
    }

    int rotate = rotateStr.toInt();
    long coord = coordStr.toInt();

    coords(*joint, rotate, coord);
    return;
  }

  // home(J1)
  if (cmd.startsWith("home(") && cmd.endsWith(")")) {
    int start = cmd.indexOf('(');
    int end = cmd.lastIndexOf(')');
    String jointName = cmd.substring(start + 1, end);

    Joint* joint = getJointByName(jointName);
    if (joint == nullptr) {
      Serial.println("Invalid joint. Use J1, J2, or J3.");
      return;
    }

    homing(*joint, 10);   // smaller step size is safer for homing
    return;
  }

  // open()
  if (cmd == "open()") {
    GripperOpen();
    return;
  }

  // close()
  if (cmd == "close()") {
    GripperClose();
    return;
  }

  // flip()
  if (cmd == "flip()") {
    FlipGripper();
    return;
  }

  // pos()
  if (cmd == "pos()") {
    printPositions();
    return;
  }

  if (cmd == "cameraPose()") {
    cameraPose();
    return;
  }
  Serial.println("Unknown command.");
}

//delete
void readSerialInput() {
  while (Serial.available()) {
    char inChar = (char)Serial.read();

    if (inChar == '\n' || inChar == '\r') {
      if (inputString.length() > 0) {
        stringComplete = true;
      }
    } else {
      inputString += inChar;
    }
  }
}


void loop() {
  readSerialInput();

  if (stringComplete) {
    executeCommand(inputString);
    inputString = "";
    stringComplete = false;
  }
}

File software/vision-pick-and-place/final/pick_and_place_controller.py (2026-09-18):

import time
import serial

# Standard imports
import os
import cv2
import numpy as np

import requests
from datetime import datetime
from pathlib import Path

# convert coordinates
def camera_to_robot(xc, yc):
    xc = float(xc)
    yc = float(yc)

    # clamp camera values
    xc = max(30.0, min(250.0, xc))
    yc = max(30.0, min(200.0, yc))

    print(f"Clamped camera coordinates: x={xc}, y={yc}")

    xr = 2500.0 + (xc - 30.0) * 4500.0 / 220.0
    yr = (yc - 30.0) * 7000.0 / 170.0
    
    print(f"Mapped robot coordinates: x={int(round(xr))}, y={int(round(yr))}")

    # deduction
    t = (200.0 - yc) / 185.0
    y_deduction = 1000.0 * (t ** 0.8)

    yr -= y_deduction

    #y_deduction = 250.0 * (200.0 - yc) / 185.0
    #yr = yr - 250.0
    
    yr = max(0.0, min(7000.0, yr))
    print(f"Mapped deducted robot coordinates: x={int(round(xr))}, y={int(round(yr))}")

    return int(round(xr)), int(round(yr))

# get image from ESP32
ESP32_URL = "http://172.20.10.2/capture"


# hough_out = "hough_circles.png"
# cv2.imwrite(hough_out, im_color)



SERIAL_PORT = "COM10"
BAUD_RATE = 115200
TIMEOUT = 40

# -----------------------------
# SPEEDS
# -----------------------------
J1_SPEED = 250
J2_SPEED = 300
J3_SPEED = 25

# -----------------------------
# IMPORTANT POSITIONS
# Change these easily later
# -----------------------------
J3_PICK_DOWN = 700
J3_DROP_HEIGHT = 100
J3_HOME_UP = 0

CAM_J1 = 4000
CAM_J2 = 7500
CAM_J3 = 0

DROP_J2 = 10150

# -----------------------------
# DELAYS
# -----------------------------
START_DELAY = 1.0
OPEN_DELAY = 1.0
DOWN_DELAY = 1.0
GRAB_DELAY = 1.0
LIFT_DELAY = 2.0
FLIP_DELAY = 1.5
PRE_DROP_DELAY = 1.0
DROP_DELAY = 1.0
POST_DROP_CLOSE_DELAY = 0.5
POST_DROP_LIFT_DELAY = 1.5
HOME_DELAY = 1.0
FINAL_DELAY = 1.0

MAX_X_ROBOT = 7150
EDGE_Y_THRESHOLD = 1000


def read_available_lines(arduino, duration=1.5):
    end_time = time.time() + duration
    while time.time() < end_time:
        while arduino.in_waiting > 0:
            line = arduino.readline().decode(errors="ignore").strip()
            if line:
                print(f"Arduino: {line}")
        time.sleep(0.02)


def wait_for_done(arduino, timeout=TIMEOUT):
    start_time = time.time()

    while time.time() - start_time < timeout:
        if arduino.in_waiting > 0:
            line = arduino.readline().decode(errors="ignore").strip()

            if line:
                print(f"Arduino: {line}")

            if line == "DONE":
                return True

            if line.startswith("ERROR"):
                raise RuntimeError(line)

        time.sleep(0.02)

    raise TimeoutError("Timed out waiting for Arduino DONE response")


def send_command(arduino, cmd, timeout=TIMEOUT):
    arduino.write((cmd + "\n").encode())
    arduino.flush()
    print(f"Sent: {cmd}")
    wait_for_done(arduino, timeout)


arduino = None

try:
    arduino = serial.Serial(SERIAL_PORT, BAUD_RATE, timeout=1)
    time.sleep(3)
    arduino.reset_input_buffer()
    arduino.reset_output_buffer()

    read_available_lines(arduino, duration=1.0)

    # -----------------------------
    # START SAFE / HOME
    # -----------------------------
    send_command(arduino, "close()")
    send_command(arduino, "home(J1)")
    send_command(arduino, "home(J2)")
    send_command(arduino, "home(J3)")

    # Flip is ONLY allowed at true J3 home
    send_command(arduino, "flipUp()")
    time.sleep(START_DELAY)

    # -----------------------------
    # MOVE TO CAMERA POSITION
    # -----------------------------
    send_command(arduino, f"coords(J1,{J1_SPEED},{CAM_J1})")
    send_command(arduino, f"coords(J2,{J2_SPEED},{CAM_J2})")
    send_command(arduino, f"coords(J3,{J3_SPEED},{CAM_J3})")

    print("At camera position, flip UP.")
    time.sleep(5.0)


    # -----------------------------
    # get cylinder location
    # -----------------------------
    response = requests.get(ESP32_URL)
    with open("board.jpg", "wb") as f:
        f.write(response.content)

    # read image
    path = "board.jpg" 
    if not os.path.isfile(path):
        raise FileNotFoundError(f"Image not found: {path}")

    im = cv2.imread(path, cv2.IMREAD_GRAYSCALE)
    if im is None:
        raise RuntimeError(f"cv2.imread failed to load the image: {path}")

    # process image 
    # filter: grayscale median blur 
    im_blur = cv2.GaussianBlur(im, (9, 9), 2)

    # detect cylinder
    # filter: hough circles detection
    circles = cv2.HoughCircles(
        im_blur,            # the blurred grayscale input image
        cv2.HOUGH_GRADIENT, # detection method
        dp=1.2,
        minDist=80,         # minimum distance between the centers of detected circles.
        param1=100,         # edge detector threshold
        param2=20,          # accumulator threshold 
        minRadius=10,       
        maxRadius=20,      
    )

    # output
    im_color = cv2.cvtColor(im, cv2.COLOR_GRAY2BGR)
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

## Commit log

2026-09-18 Document Autonomous Cylinder Pick System (Group 16 mechatronics project)
    Add final firmware, vision pipeline, iteration history, CAD exports,
    task/requirements breakdown, and project presentations/media.
    [attachment-point.stl, base-gear-update.stl, base-gear.stl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]
2026-09-18 Reorganize repo into hardware/software/firmware/evidence
    Regroup the flat firmware/vision-system/cad/docs/media/results layout
    into four top-level folders by kind of work: firmware/ (ESP32 code for
    both boards), software/ (host-side vision + pick-and-place controller),
    hardware/ (CAD exports + datasheets), and evidence/ (documentation,
    presentations, measurements, and build/test photos and video).
    Update all cross-references and add a short README to each top-level
    folder as an index.
    [attachment-point.stl, base-gear-update.stl, base-gear.stl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]
2026-09-18 Retitle README and add STAR-style project sections
    Set the title to "3rd year Mechatronics group project" and add Project
    aim / tasks / objectives / outcomes sections grounded in the CW2
    coursework brief (25WSC912 Mechatronics and Instrumentation — Design
    and Build of a Disc Flipping and Positioning Mechanism), replacing the
    looser "What it does" walkthrough.
2026-09-18 Trim root README to a narrative overview, move details into subfolders
    Move the hardware list, per-file architecture table, demo photo list,
    and inclusion notes out of the root README and into the relevant
    firmware/software/hardware READMEs (already the natural home for that
    detail). Replace the link-heavy architecture table with a proper
    written explanation of the mechanical layout, arm control firmware,
    vision pipeline, and the two-loop serial handshake that ties them
    together.
    Rename the two "final" deliverable files to something a reader can
    tell apart from the iteration history at a glance:
    FINALONE.ino -> arm_controller.ino,
    FINALCODEMAX.py -> pick_and_place_controller.py.
    [arm_controller.ino, pick_and_place_controller.py]
2026-09-18 Split documentation into tasks/requirements/gantt-chart/architecture
    Remove the intro block above Project aim in the root README.
    Split evidence/documentation/tasks-and-requirements.md into separate
    tasks.md and requirements.md, and rename architecture.md to
    architecture-workflow.md. Replace gantt-chart.xlsx with a simplified
    gantt-chart.md that drops dates/status and keeps just task + owner,
    filling in previously-unassigned tasks and adding two tasks that were
    actually built but missing from the original plan (edge-case pick
    routine, flip/drop safety interlocks).
    Call out robot-control-logic.pdf as my own slides and individual
    contribution to the group presentation.
    [gantt-chart.xlsx]
